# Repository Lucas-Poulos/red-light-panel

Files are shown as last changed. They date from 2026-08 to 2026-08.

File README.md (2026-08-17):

# red-light-panel

A battery-powered 660nm red light therapy panel. 4S2P 18650 Li-ion pack
(~74Wh-class), USB-C PD charging, ~74W LED load across two independently
PWM-dimmable channels, STM32-based control with a 4-button HMI.

KiCad 10 hardware project — schematic + BOM. PCB placement/routing is
out of scope for this pass, but the board is fab-ready to route against:
2-layer, 1oz/1oz copper, JLCPCB-standard-service design rules with
margin (not run at the fabrication limit) — see
`docs/pcb_fabrication_rules.md` for the exact values and rationale.
All 153 components are imported onto the board from the schematic.

## Architecture

Seven hierarchical sheets, numbered so KiCad's hierarchy navigator sorts
them in build/reading order:

| Sheet | Description |
|---|---|
| `01_battery_protection` | 4S2P 18650 pack, BQ76920 protection AFE, high-side dual-FET protection, reverse-polarity guard |
| `02_usbc_charging` | USB-C PD input (TPS25751), buck-boost charger (BQ25792), ESD protection |
| `03_power_rail_3v3` | TPS563201 buck regulator, 3.3V system logic rail |
| `04_led_drivers` | 2x LM3409HV PFET-buck constant-current LED driver channels |
| `05_led_array` | 64x Luminus SST-10-DR-B130-K660 660nm LEDs, 2 channels x 8 parallel x 4 series strings |
| `06_mcu_control` | STM32G031K8T6 MCU, SWD debug (Cortex Debug 10-pin + THT breakout), ESD arrays |
| `07_hmi` | 4 tactile buttons (power/dim+/dim-/mode), single-color status LED |

Connectivity uses `GlobalLabel`s throughout rather than wired
hierarchical sheet-symbol pins — see `docs/design_notes.md` for why. The
root sheet (`red-light-panel.kicad_sch`) contains only the 7 sheet
symbols, no components.

## Opening the project

Requires **KiCad 10**. Clone the repo and open `red-light-panel.kicad_pro`
— the project-local `sym-lib-table`/`fp-lib-table` register every stock
library this design uses (via `${KICAD10_SYMBOL_DIR}`/
`${KICAD10_FOOTPRINT_DIR}`, so they resolve on any machine with KiCad 10
installed) plus `libs/red-light-panel.kicad_sym` / `.pretty` for the
handful of parts not in KiCad's stock libraries. No global library setup
is required.

## Regenerating the schematics

The 7 sub-sheets and the root sheet are generated programmatically from
`tools/kicad_gen/` (a small `kiutils`-based builder), not hand-drawn —
see `docs/design_notes.md` "Schematic generation approach" for the full
pipeline and the non-obvious KiCad file-format details it works around.
To rebuild everything from the declarative part lists in
`tools/kicad_gen/sheet*.py`:

```
pip install kiutils sexpdata
python3 tools/kicad_gen/sheet1.py   # ... through sheet7.py
python3 tools/kicad_gen/root_sheet.py
python3 tools/kicad_gen/fix_instance_paths.py
```

## Regenerating the BOM

```
python3 bom/generate_bom.py
```

Wraps `kicad-cli sch export bom` (reads the full hierarchical netlist
including the custom `MPN`/`Manufacturer`/`DigiKey_PN`/`Sheet` fields set
on every symbol) grouped by `(MPN, Value, Footprint)` into
`bom/red-light-panel-bom.csv` — 48 rows, 153 total placed components.

## Current design status

**Verification**: full-hierarchy `kicad-cli sch erc` on
`red-light-panel.kicad_sch` reports **0 errors** (157 cosmetic
"endpoint off grid" warnings from the auto-placed layout, 3 expected
"lib_symbol_mismatch" warnings from stock parts whose KiCad-library
`extends` chain was flattened for pin-position reliability — see
`docs/design_notes.md`). Every one of the 153 placed components has a
linked footprint; zero duplicate reference designators.

### Known open items (flagged, need your review before fab)

**Corrections to the original BOM** (verified real part numbers/topology
fixes, not silent substitutions to different components):
- `TPD4S012DBVR` → **TPD4S012DRYR** (that BVR suffix/package doesn't
  exist for this part; TI only makes it in a 6-pin USON).
- `TPD4E001DZDR` → **TPD4E001DBVR** (same issue; the 4-channel device
  needs a 6-pin SOT-23, not the 4-pin DZD package).
- `TPS25750DRYR` → **TPS25751DREFR** (TPS25750 is TI-marked
  Not-Recommended-for-New-Designs; TPS25751 is the active replacement —
  your decision, see below).
- Fuse `MICROSMD250F/16-2` (originally a placeholder) → **Bel Fuse
  0ZRE0025FF** (0.25A hold current, matching the placeholder's own naming
  convention) — verify hold-current spec against your real current
  budget before finalizing.
- Status LED `APTD1608LSECK/J4-PRV` → confirmed **single-color**
  (`APT1608LSECK/J4-PRV`, no "D") — no real bi-color part exists under
  that family name. Per your decision, D71 (renumbered from D8, see
  below) is now a single-color status LED.
- Reference designators **D6/D7/D8 renumbered to D69/D70/D71**: the
  original BOM's own `D5-D68` (64 LED array elements) numerically
  collided with these three (sheet 6 ESD arrays, sheet 7 status LED).

**Needs your engineering review** (reasonable, documented, but
unverified-against-datasheet or genuinely open decisions):
- **BQ25792's front-end ideal-diode MOSFETs (ACFET/RBFET1/RBFET2) are not
  included** — TI's real reference design needs them on the
  ACDRV1/ACDRV2/BTST1/BTST2 pins, but they weren't itemized in the
  original BOM and weren't invented here unprompted. The charger's
  reverse-blocking front-end is incomplete as generated until you decide
  whether/how to add this.
- **TPS25751DREFR and BQ25792RQMR are hand-built symbols** (no official
  downloadable KiCad source exists for either — confirmed via TI/DigiKey/
  Ultra Librarian). Every pin was sourced from TI's own datasheet pin
  tables, but several individual pins have ambiguous datasheet electrical
  types (TI itself labels some pins as generic "P"/"I/O") — double-check
  before trusting blind, especially: TPS25751's `LDO_1V5`/`DRAIN`/`PPHV`/
  `VBUS_IN`; BQ25792's `BTST1`/`BTST2`/`VAC1`/`VAC2`/`BATP`/`BAT`/`PMID`.
- **TPS25751's power-path topology** (VBUS_IN → internal switch →
  PPHV/DRAIN → BQ25792) is a best-effort interpretation of TI's own
  ambiguous datasheet, not confirmed against a real TI reference design.
- **LED array topology** (8 parallel strings of 4 series LEDs per
  channel, ~625mA/string) is derived from Vf/rail-voltage math, not
  specified by the BOM — verify against the ~74W target power budget and
  the Luminus datasheet's thermal-derating curves.
- **STM32G031 GPIO assignment** (I2C on PB6/PB7, PWM on PA6/PA7, buttons
  on PA0-PA3, NTC ADC on PA4, NRST on PF2) is a reasonable but
  **unverified-against-the-reference-manual** pin choice.
- **Driver inductors** (L2/L3, Vishay IHLP2525CZERR10M01) and the 3.3V
  rail inductor (L1, Wurth 744031220) — values need a real switching-
  frequency calc against LM3409HV's/TPS563201's design equations, not
  just the default values used here.
- **L1's footprint** is a size-matched placeholder (no exact Wurth
  744031220 footprint exists in KiCad's stock libraries).
- **J3's exact GCT USB4105 suffix** (plating/stake length) — defaulted
  to `USB4105-GF-A`; there is no "mount style" suffix (confirmed via
  research — the whole series is one fixed SMT top-mount style).
- **J6's footprint** (generic 2x5 1.27mm SMD header) is electrically
  equivalent to but not the exact Samtec FTSH-105-01-F-DV-K footprint.
- **Calculated component values** flagged inline in their `Value` field
  wherever a real datasheet equation was used instead of an itemized BOM
  value: R3 (3.3V feedback divider bottom leg), R13 (status LED current
  limit), and every "(added, flagged)" support passive (COFF/UVLO
  networks, bootstrap caps, ILIM_HIZ/PROG set resistors, NTC pull-up) —
  see `tools/kicad_gen/sheet*.py` docstrings for the reasoning behind
  each.

None of the above are unresolved *nets* or missing pin connections —
every flagged item is a component-value/part-choice judgment call called
out for your review, consistent with a 0-error ERC pass.

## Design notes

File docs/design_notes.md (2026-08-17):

# Design notes

Working notes on non-obvious decisions made while generating this project,
kept here so they don't get lost or re-litigated later.

## Schematic generation approach

All 7 sub-sheets (and the root sheet) are generated programmatically from
`tools/kicad_gen/` rather than hand-drawn in the KiCad GUI, because the
BOM is large (~150 placed parts) and this keeps the part list, footprint
assignment, and wiring declarative and re-runnable. See
`tools/kicad_gen/builder.py` for the implementation; each `tools/kicad_gen/sheetN.py`
defines that sheet's parts and nets and calls into the shared builder.

You can still open and edit the resulting `.kicad_sch` files normally in
the KiCad 10 GUI -- the generator is just how they were first populated.

### Pipeline

1. Build the schematic object model with `kiutils` (a mature Python KiCad
   file library that targets the KiCad 8-era file format).
2. Text-patch two gaps between what kiutils emits and what KiCad 10 needs
   to load the file at all: quote the `generator` token and add a
   `generator_version` line (kiutils doesn't emit this token), and quote
   bare UUID-shaped tokens (kiutils doesn't quote them; KiCad 10's loader
   rejects the file outright without quotes).
3. Run `kicad-cli sch upgrade --force` to have the real KiCad 10 binary
   rewrite the file to its true native format. This is the authoritative
   normalization step -- nothing about the final file format is guessed.

### Connectivity: global labels, no wires

Every pin that needs to be on a net gets a `GlobalLabel` placed exactly at
that pin's world coordinate -- no wires anywhere. Two labels with the same
text are the same net project-wide even with zero wires between them, as
long as each is coincident with a real pin. This is standard KiCad
behavior (confirmed against a real kicad-cli 10.0.5 install and
cross-checked against a prior project's own ERC-clean, wire-free
schematics) and avoids hand-routing ~150 components.

**Global, not local, labels.** `LocalLabel` empirically did *not* connect
to a coincident pin in this KiCad version without an explicit wire
touching both -- only `GlobalLabel` (and, by extension, hierarchical
labels) connect by bare coincidence. Since every net name used here is
unique to its sheet except the intentionally-shared cross-sheet nets
(VBAT, GND, I2C_SDA, ...), using global scope throughout carries no risk
of accidental cross-sheet merges.

**Why global labels instead of sheet-symbol pins.** The prompt that
originated this project asked for literal hierarchical labels + matching
sheet-symbol pins on the root sheet for inter-sheet nets. Global labels
achieve the identical electrical outcome (a net crosses sheet boundaries
by name, project-wide) with far less risk -- no need to hand-place
sheet-symbol pins and wire them to matching labels on the root sheet, and
no chance of a sheet-pin/hierarchical-label name or direction mismatch.
The root sheet's sheet symbols carry no pins as a result; this is a
deliberate, documented substitution, not an oversight.

**Power nets use real power symbols, not bare labels.** GND, VBAT,
VBAT_PROT, 3V3, and USB_VBUS are placed as actual KiCad power symbols
(`power:GND`, `power:+3V3` with its Value overridden to "3V3",
`power:VBUS` overridden to "USB_VBUS", and two custom symbols for VBAT/
VBAT_PROT copied from stock `power:+BATT` into
`libs/red-light-panel.kicad_sym`) rather than plain `GlobalLabel`s -- the
idiomatic convention a human designer would use for rails specifically.
`add_power_symbol()` in `builder.py` places one at every pin on these
nets, same coincidence-based mechanism as the flying-label technique
above (confirmed empirically that overriding a stock power symbol's
Value *does* change its effective net name -- e.g. `power:+3V3` with
Value "3V3" correctly nets as "3V3", not "+3V3" -- as long as the symbol
is actually coincident with a real pin; an isolated power symbol
touching nothing is, unsurprisingly, still just as disconnected as an
isolated label would be). Every stock/custom power symbol's pin is type
`power_in`, never `power_out`, so this doesn't change anything about the
PWR_FLAG requirements below. All other cross-sheet/signal nets
(I2C_SDA, PWM_A, LED_A+, ...) remain plain `GlobalLabel`s -- a "power
symbol" wouldn't make semantic sense for a data or PWM signal.

**The pin-position Y-flip.** A pin's world connection point is
`(symbol.x + pin.local_x, symbol.y - pin.local_y)` -- note the minus sign.
KiCad's symbol library editor uses a Y-up coordinate system internally,
but placed schematic coordinates are Y-down, so the Y axis flips when a
symbol is placed. Confirmed empirically (a naive `+` produced schematics
where every single pin was reported "not connected" by
`kicad-cli sch erc`, despite the labels looking coincident on paper) and
cross-checked against a real, ERC-clean prior project's file. Pin `length`
is *not* added -- the pin's own `(at x y)` already is the connection tip
in the library data kiutils exposes.

**Flattening `extends`-based symbols.** A handful of stock symbols
(`Transistor_FET:AO3401A` extends `TP0610T`, `CSD18540Q5B` extends
`Q_NMOS_SSSGD_AvalancheRated`) are defined via KiCad's `extends`
mechanism to avoid duplicating a shared body/pinout. Embedding both the
derived and base symbols in a sheet's `lib_symbols` cache (with the base's
library correctly registered in the project's own `sym-lib-table`) loads
fine and only produces the expected benign `lib_symbol_mismatch` ERC
warning -- but pin *position* resolution for the still-`extends`-linked
placed instance did not reliably line up with the raw coordinates pulled
from the base symbol: every pin on every `extends`-based part came back
as a dangling label. `load_stock_symbol()` in `builder.py` works around
this by flattening -- copying the base's units directly onto the derived
symbol and dropping the `extends` pointer before embedding, so pin data
always comes from the one object that's actually placed. A prior project
independently hit and documented the same class of problem (there, the
proximate cause was an unregistered library nickname rather than a
pin-position mismatch, but the fix -- flatten `extends` rather than rely
on it -- is the same).

### PWR_FLAG placement

`kicad-cli sch erc`'s `power_pin_not_driven` check requires every
`power_in`-type pin's net to have some `power_out`-type pin (or a
`Device:PWR_FLAG`) on it *somewhere in the whole hierarchical project*.
Rails that are genuinely sourced off-sheet from that sheet's own
perspective (e.g. `VBAT` and `GND` on the battery sheet, which are
sourced by the cell stack itself and by downstream loads respectively, not
by any `power_out` pin placed on that sheet) get a `PWR_FLAG` so this
check doesn't misfire. `PWR_FLAG` symbols are placed with `in_bom no` /
`on_board no`, matching KiCad convention -- they're a paper annotation for
ERC, not a real component.

**Exactly one `PWR_FLAG` per net, project-wide.** Placing one per sheet
(the initial approach, since each sheet's ERC was validated standalone
before the root hierarchy existed) breaks at full-hierarchy scale: two or
more `PWR_FLAG`s on the same merged global-label net trigger their own
`pin_to_pin` "Power output and Power output are connected" error against
each other. Also: a pin typed `output` (e.g. a buck regulator's `SW` pin)
does *not* satisfy `power_pin_not_driven` the way a `power_out`-typed pin
does -- don't assume a rail is "genuinely driven" without checking the
actual electrical type of the pin that's supposed to be driving it.

**Each `PWR_FLAG`'s `Reference` must be unique project-wide.** Every
instance defaulting to the literal `#FLG` (rather than an
auto-incrementing `#FLG1`, `#FLG2`, ...) is invisible to `kicad-cli sch
erc` but trips `kicad-cli sch export bom`'s annotation check once more
than one exists across the hierarchy -- a real KiCad GUI session
auto-numbers these the first time you run Annotate, but nothing here ever
calls that, so `add_pwr_flag()` takes an explicit `flag_id` argument.

### Root sheet: per-symbol `instances` blocks

`kicad-cli sch upgrade --force` (used while generating/validating each
sheet standalone, before the root sheet existed) silently drops every
placed symbol's `(instances (project ...))` block down to an empty
`(instances)` -- observed empirically, not something this project's code
or kiutils ever asked it to do. That's invisible to ERC (which works from
raw geometry) but is exactly what `kicad-cli sch export bom` flags as
"schematic has annotation errors": each symbol's project-instance
bookkeeping (which sheet-instance path it belongs to) was empty.
`tools/kicad_gen/fix_instance_paths.py` is a one-time pass, run after the
root sheet exists, that populates the real path
(`/<root-uuid>/<this-sheet's-uuid-on-the-root-sheet>`) via direct text
surgery -- round-tripping an already-v10-upgraded file back through
kiutils was tried first and rejected: kiutils' parser doesn't fully
understand the v10 format `kicad-cli` produces and silently drops most of
the file's content on that round-trip (a 6,300-line file came back as
~2,100 lines with no error raised).

### Reference-designator collision in the original BOM

The brief's own BOM has a numbering collision: `D5-D68` (64 LED array
elements, sheet 5) numerically includes `D6`/`D7` (sheet 6's ESD arrays)
and `D8` (sheet 7's status LED). Resolved by keeping the LED array's
documented range intact (it has an exact count constraint: 68-5+1=64) and
renumbering the other three to `D69`/`D70`/`D71` instead. Flagged in each
affected sheet's build-script docstring.

## Flagged additions beyond the literal BOM

A few passives are required by the datasheet-mandated minimum application
circuit for a listed IC, but weren't itemized as separate BOM rows in the
original part list. These are called out with `(added, flagged)` in their
`Value` field and documented per-sheet in that sheet's build script
docstring (`tools/kicad_gen/sheetN.py`) so they're easy to find and
double-check. See also the top-level `README.md` "Known open items" list.

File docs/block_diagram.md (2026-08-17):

# Block diagram

Placeholder — a visual block diagram should go here (e.g. exported from
the KiCad hierarchy or drawn separately). Textual summary of the signal
flow in the meantime:

```
USB-C (J3) ──► TPS25751 (PD sink + power path) ──► BQ25792 (buck-boost charger) ──► VBAT
                                                                                        │
4S2P 18650 pack ───────────────────────────────────────────────────────────────────────┤
                                                                                        ▼
                                                              BQ76920 (protection AFE)
                                                              + high-side dual-FET guard
                                                                                        │
                                                                                        ▼
                                                                                  VBAT_PROT
                                                                                        │
                                        ┌───────────────────────────────────────────────┼──────────────┐
                                        ▼                                               ▼              ▼
                              TPS563201 (3.3V buck)                          LM3409HV x2 (LED drivers, PWM_A/PWM_B from MCU)
                                        │                                               │
                                        ▼                                               ▼
                          STM32G031K8T6 (MCU) ◄──── HMI (4 buttons)          LED array (64x 660nm, 2ch x 8 parallel x 4 series)
                                        │
                                        ▼
                                 SWD debug (J6/J7)
```

Fill in with the actual rationale/tradeoffs discussed separately once
available (referenced in the original project brief as "I'll fill in
details from our chat separately").

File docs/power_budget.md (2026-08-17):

# Power budget notes

Placeholder — rough, back-of-envelope numbers derived while generating
the schematic (see `tools/kicad_gen/sheet4.py` and `sheet5.py` docstrings
for the full reasoning). **Not a substitute for a real power budget
pass** — flagged throughout as needing verification against the actual
Luminus SST-10-DR datasheet current/thermal-derating curves and your
real target runtime.

## LED load

- 64x Luminus SST-10-DR-B130-K660, split into 2 channels (LM3409HV
  drivers) x 8 parallel strings x 4 series LEDs.
- ~2.1V Vf per LED (typ., 660nm deep red) → ~8.4V per string.
- LM3409HV/R4-R5 sense resistor (0.02ohm, ~100mV typ. threshold) sets
  ~5A total channel current → ~625mA per string/per LED.
- Per-channel: ~8.4V x 5A ≈ 42W. Two channels ≈ **84W** -- in the same
  ballpark as the brief's own "~74W LED load" figure but not an exact
  match; needs reconciling against your actual target (adjust the sense
  resistor value or string count to dial in the real target current).

## Battery pack

- 4S2P 18650 (e.g. Samsung INR18650-30Q, ~3000mAh/cell) → ~6000mAh pack
  capacity at nominal 14.4V (3.6V/cell) → **~86Wh** pack energy.
- At ~84W LED load alone (both channels, ignoring MCU/driver overhead),
  that's roughly **~1 hour** of runtime at full brightness/both channels
  -- worth checking against your actual intended treatment-session
  duration and duty cycle (PWM dimming via EN on the LM3409HV channels
  will reduce average draw well below this worst-case number in normal
  use).

## Charging

- BQ25792 buck-boost charger, USB-C PD input via TPS25751. Real charge
  current depends on the PD contract negotiated (not modeled here) and
  the ILIM_HIZ/PROG resistor values (R91/R92, flagged as placeholders in
  `sheet2.py` -- calculate against your real target charge current).

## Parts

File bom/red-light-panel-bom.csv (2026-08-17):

Reference | Value | MPN | Manufacturer | DigiKey_PN | Qty | Sheet
BT1,BT2,BT3,BT4,BT5,BT6,BT7,BT8 | INR18650-30Q | Samsung INR18650-30Q | Samsung SDI | INR18650-30Q-B-ND | 8 | 1
C1,C2,C6,C12,C13 | 10uF | CC1206KKX7R8BB106 | Yageo | 311-4622-1-ND | 5 | 2,3,4
C3,C4,C5,C8,C9,C10,C11,C14,C15,C16,C17 | 0.1uF | CC0603KRX7R9BB104 | Yageo | 311-1367-1-ND | 11 | 2,4,6
C7 | 10uF | CC1206KKX5R7BB106 | Yageo | 311-4633-1-ND | 1 | 3
C18 | 4.7uF | CC1206KKX7R8BB475 | Yageo | 311-4646-1-ND | 1 | 6
C90 | 1uF (added, flagged) |  |  |  | 1 | 1
C91 | 0.1uF (added, flagged) |  |  |  | 1 | 1
C92 | 1uF (added, flagged -- PMID bulk cap per typical app circuit) |  |  |  | 1 | 2
C93 | 2.2nF (added, flagged -- VBST bootstrap cap) |  |  |  | 1 | 3
C94,C95 | 100pF (added, flagged -- COFF timing, calc vs L freq) |  |  |  | 2 | 4
D1 | SMAJ24CA | SMAJ24CA | Littelfuse | F5351CT-ND | 1 | 1
D2 | TPD4S012DRYR (corrected from BOM's TPD4S012DBVR -- flag) | TPD4S012DRYR | Texas Instruments | 296-TPD4S012DRYRCT-ND | 1 | 2
D3,D4 | SS54 | SS54 | onsemi/Diodes Inc (generic SS54) | SS54-E3/57TCT-ND | 2 | 4
D5,D6,D7,D8,D9,D10,D11,D12,D13,D14,D15,D16,D17,D18,D19,D20,D21,D22,D23,D24,D25,D26,D27,D28,D29,D30,D31,D32,D33,D34,D35,D36,D37,D38,D39,D40,D41,D42,D43,D44,D45,D46,D47,D48,D49,D50,D51,D52,D53,D54,D55,D56,D57,D58,D59,D60,D61,D62,D63,D64,D65,D66,D67,D68 | SST-10-DR-B130-K660 | SST-10-DR-B130-K660 | Luminus Devices | 1462-SST-10-DR-B130-K660-ND (verify exact reel/tape SKU) | 64 | 5
D69,D70 | TPD4E001DBVR (corrected from BOM's TPD4E001DZDR -- flag) | TPD4E001DBVR | Texas Instruments | 296-TPD4E001DBVRCT-ND | 2 | 6
D71 | APT1608LSECK/J4-PRV (single-color, corrected per your decision) | APT1608LSECK/J4-PRV | Kingbright | 754-1552-1-ND | 1 | 7
F1 | 0.25A resettable | 0ZRE0025FF (corrected from placeholder MICROSMD250F/16-2 -- FLAG FOR REVIEW) | Bel Fuse | 507-1677-1-ND | 1 | 1
J1 | JST B5B-XH-A | B5B-XH-A | JST | 455-1719-ND | 1 | 1
J2 | Molex 43045-0200 | 43045-0200 | Molex | WM1857-ND | 1 | 1
J3 | USB4105-GF-A (plating/stake length TBD, flag) | USB4105-GF-A | GCT | GCT USB4105-GF-A-ND (verify exact DigiKey SKU) | 1 | 2
J4,J5 | 2-pin screw terminal / JST-PH-2 | B2B-PH-K-S(LF)(SN) | JST | 455-1728-ND | 2 | 5
J6 | Cortex Debug 10-pin | FTSH-105-01-F-DV-K (footprint substituted, flag) | Samtec | SAM8199-ND | 1 | 6
J7 | Debug breakout (SWDIO,SWCLK,NRST,3.3V,GND) | PREC005SAAN-RC | Sullins | S7036-ND | 1 | 6
L1 | 2.2uH (Wurth 744031220) | 744031220 | Wurth Elektronik | 732-1801-1-ND | 1 | 3
L2,L3 | IHLP2525CZERR10M01 (0.10uH) | IHLP2525CZERR10M01 | Vishay Dale | 541-2724-1-ND | 2 | 4
L90 | 2.2uH (added, flagged -- calc vs target charge current) |  |  |  | 1 | 2
Q1,Q2 | CSD18540Q5B | CSD18540Q5B | Texas Instruments | 296-37312-1-ND | 2 | 1
Q3 | AO3401A | AO3401A | Alpha & Omega Semiconductor | AO3401A-DICT-ND | 1 | 1
Q4,Q5 | AO3401A (30V Vds, satisfies brief's margin flag) | AO3401A | Alpha & Omega Semiconductor | AO3401A-DICT-ND | 2 | 4
R1 | 0.01R 1% | WSL2512R0100FEA | Vishay Dale | 541-2455-1-ND | 1 | 1
R2,R6,R7,R8,R9,R10,R11,R12 | 10k | RC0603FR-0710KL | Yageo | 311-10.0KHRCT-ND | 8 | 3,6,7
R3 | 3.01k (calc, flag) | RC0603FR-073K01L | Yageo | 311-3.01KHRCT-ND | 1 | 3
R4,R5 | 0.02R 1% | WSL2512R0200FEA | Vishay Dale | 541-2456-1-ND | 2 | 4
R13 | 680R (calc vs Vf/If, flag) | RC0603FR-07680RL | Yageo | 311-680HRCT-ND | 1 | 7
R90 | 100k | RC0603FR-07100KL | Yageo | 311-100KHRCT-ND | 1 | 1
R91 | 10k (added, flagged -- ILIM_HIZ set resistor, calc per datasheet eqn) |  |  |  | 1 | 2
R92 | 4.7k (added, flagged -- PROG set resistor, calc per datasheet eqn) |  |  |  | 1 | 2
R94,R96 | 100k (added, flagged -- COFF timing, calc vs L freq) |  |  |  | 2 | 4
R95,R97 | 100k (added, flagged -- UVLO always-on pull-up, no set threshold) |  |  |  | 2 | 4
R98 | 10k (added, flagged -- NTC divider pull-up) |  |  |  | 1 | 5
RT1 | NCP18XH103F03RB (10k NTC) | NCP18XH103F03RB | Murata | 490-16279-1-ND | 1 | 5
SW1,SW2,SW3,SW4 | Omron B3U-1000P | B3U-1000P | Omron | SW1020CT-ND | 4 | 7
U1 | BQ76920PW | BQ7692000PWR | Texas Instruments | 296-37299-1-ND | 1 | 1
U2 | TPS25751DREFR (active replacement for NRND TPS25750DRYR, per your decision) | TPS25751DREFR | Texas Instruments | 296-TPS25751DREFR-ND (verify) | 1 | 2
U3 | BQ25792RQMR | BQ25792RQMR | Texas Instruments | 296-BQ25792RQMR-ND (verify) | 1 | 2
U4 | TPS563201DDCR | TPS563201DDCR | Texas Instruments | 296-51654-1-ND | 1 | 3
U5,U6 | LM3409HVMY/NOPB | LM3409HVMY/NOPB | Texas Instruments | 296-30489-1-ND | 2 | 4
U7 | STM32G031K8T6 | STM32G031K8T6 | STMicroelectronics | 497-STM32G031K8T6TR-ND | 1 | 6

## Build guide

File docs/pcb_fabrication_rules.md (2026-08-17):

# PCB fabrication rules — 2-layer, 1oz/1oz, JLCPCB standard service + margin

This board is configured as a standard (non-advanced/non-HDI) 2-layer
JLCPCB build, with every constraint set comfortably above JLCPCB's
published minimum capability rather than at the limit. Two places hold
the actual rule values:

- **`red-light-panel.kicad_pro`** (`board.design_settings.rules` and
  `net_settings.classes`) — board-wide minimums, edited in KiCad's own
  "Board Setup > Design Rules > Constraints" schema.
- **`red-light-panel.kicad_dru`** — net-specific overrides for
  high-current traces (KiCad auto-loads this because its filename
  matches the project name; no separate registration needed).

## Stackup

`red-light-panel.kicad_pcb`'s `(setup (stackup ...))`:

| Layer | Spec |
|---|---|
| F.Cu / B.Cu | 1oz (0.035mm) copper, both outer layers |
| Core | 1.53mm FR4 core, er=4.6, loss tangent 0.02 (JLCPCB's commonly published 2-layer 1.6mm-stackup core) |
| Overall thickness | 1.6mm (standard, matches `general.thickness`) |
| Surface finish | **ENIG**, not JLCPCB's HASL default |

**Surface finish flag**: this design has fine-pitch QFN parts (BQ25792
at 0.4mm pitch, TPS25751 also 0.4mm pitch) where HASL's uneven surface
is a real solder-bridging risk. ENIG is still a standard JLCPCB service
option (not an "advanced" surcharge tier), just a deliberate upgrade
from their default. Flip back to HASL if cost is a bigger concern than
that risk for your build.

## Board-wide DRC minimums (`kicad_pro` → `design_settings.rules`)

| Rule | JLCPCB standard-service minimum | Set here | Margin |
|---|---|---|---|
| Track width | 0.09mm (3.5mil) | **0.15mm (6mil)** | ~1.7x |
| Clearance (track/pad-to-track/pad) | 0.09mm (3.5mil) | **0.15mm (6mil)** | ~1.7x |
| Copper-to-board-edge | ~0.3mm | **0.5mm** (kept from KiCad's own default, already exceeds target) | ~1.7x |
| Hole-to-copper clearance | ~0.13mm | **0.3mm** | ~2.3x |
| Hole-to-hole spacing | ~0.25mm | **0.5mm** | 2x |
| Through-hole (PTH) diameter | ~0.2-0.3mm (board-thickness dependent) | **0.3mm** | at/above min |
| Via diameter (pad) | ~0.45mm | **0.5mm** floor / **0.6mm** preferred (net class) | modest, more via the preferred-vs-floor gap |
| Via drill | ~0.2mm | **0.3mm** (net class default) | 1.5x |
| Silk line width | ~0.1mm (4mil) | **0.15mm (6mil)** | 1.5x |
| Silk clearance | not separately specified | **0.15mm** | -- |
| Min text height | 0.8mm (legibility floor) | **1.0mm** | -- |
| Solder mask expansion | ~0.05mm typical default | **0.05mm** | matches typical, not pushed to 0 |

6mil track/clearance (not JLCPCB's bare 3.5mil minimum) is a
widely-used "PCB house safe default" across the industry generally, not
just JLCPCB-specific — it's tight enough to still be practical for this
board's finer-pitch parts, while leaving real headroom over the absolute
floor.

**Known tension, flagged rather than silently loosened**: JLCPCB's
0.4mm/0.5mm-pitch QFN parts (BQ25792, TPS25751, LM3409HV) may need
tighter local escape-routing clearance than this board-wide 0.15mm floor
allows once layout begins — that's a normal, expected situation handled
with a small *local* net-class exception for just those specific escape
traces when routing, not by loosening the global minimum for the whole
board. Not resolved here since layout hasn't started.

## Net-specific high-current overrides (`kicad_dru`)

The board-wide 0.15mm minimum is nowhere near adequate for actual
current-carrying traces — this is a real physical/thermal constraint,
not a fabrication-capability one, and needed handling regardless of the
DRC-minimum discussion above. Per `docs/power_budget.md`'s ~5A/channel
LED current and comparable pack-level current estimates, 1oz copper at
~20°C rise wants meaningfully wider traces than logic-signal minimums:

| Net group | Track width | Rationale |
|---|---|---|
| `VBAT`, `VBAT_PROT`, `GND`, `USB_VBUS`, `PD_PP_OUT` | 1.5mm (opt), 1mm (min) | Pack-level current, worst case ~5-6A |
| `LED_A+/-`, `LED_B+/-` | 1.5mm (opt), 1mm (min) | ~625mA/string x up to 8 parallel strings ≈ 5A/channel |
| `U4_SW`, `U3_SW1`, `U3_SW2` | 1mm (opt), 0.8mm (min) | Buck/charger switching nodes -- also keep these short/direct once routed, wide alone doesn't fix switching-noise loop area |

These widths are a safe starting point sized off the power-budget
estimate already flagged as needing real verification (see
`docs/power_budget.md`) — recheck once the exact target LED current is
locked in, not just before fab.

## Current DRC status

The board currently has all 153 footprints imported from the schematic
but **not yet placed or routed** (this project's stated scope stopped at
schematic + BOM — see `README.md`). Running `kicad-cli pcb drc` right
now reports several hundred violations, essentially all attributable to
that: overlapping default-import footprint placement (`shorting_items`,
`clearance`, `silk_overlap`/`silk_over_copper`), no board outline
(`invalid_outline`), and pad nets not yet synced from the schematic
(`net_conflict` under schematic-parity). None of that is caused by the
rule values above — it's expected for an unplaced/unrouted board and
will clear as layout progresses.

One **real, useful finding** the new rules did catch: **U2's WQFN-38
footprint** (`Package_DFN_QFN:Texas_REF0038A_WQFN-38-2EP_6x4mm_P0.4`)
has small thermal-relief vias in its exposed pad drilled at 0.2mm,
which is below this board's 0.3mm minimum through-hole diameter. This
is the same footprint already flagged in `README.md` as having a
pad-count-mismatch caveat from sourcing — worth resolving both issues
together when this footprint gets a closer look (either accept 0.2mm
thermal vias as a deliberate, JLCPCB-capable-but-tighter-than-our-margin
exception for just that footprint, or rebuild the thermal pad via array
at 0.3mm).

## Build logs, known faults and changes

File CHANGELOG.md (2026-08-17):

# Changelog

All notable changes to this project are documented here.

## [Unreleased]

### Added
- Initial repo scaffold: CERN-OHL-P v2 license, KiCad-appropriate
  `.gitignore`, README.
- KiCad 10 project scaffold (`red-light-panel.kicad_pro`/`.kicad_pcb`),
  project-scoped `sym-lib-table`/`fp-lib-table`.
- Programmatic schematic generator (`tools/kicad_gen/`) built on
  `kiutils`, used to populate all 7 hierarchical sub-sheets and the root
  sheet from declarative part lists.
- Full 7-sheet schematic hierarchy: Battery Pack & Protection, USB-C
  Charging Input, 3.3V Logic Rail, LED Drivers, LED Array, MCU & Control,
  HMI. 153 placed components, 0 ERC errors project-wide.
- Hand-built KiCad symbols for parts with no official downloadable source
  (`libs/red-light-panel.kicad_sym`): TPS25751DREFR, BQ25792RQMR,
  LM3409HVMY, TPD4S012DRYR, TPD4E001DBVR.
- Custom footprint for the Luminus SST-10-DR 3535-package LED
  (`libs/red-light-panel.pretty/`).
- BOM generation script (`bom/generate_bom.py`) and initial
  `bom/red-light-panel-bom.csv` (48 grouped rows).
- `docs/design_notes.md`, `docs/block_diagram.md`, `docs/power_budget.md`.

### Changed / corrected from the original part list
- `TPS25750DRYR` → `TPS25751DREFR` (NRND → active replacement).
- `TPD4S012DBVR` → `TPD4S012DRYR` (real part number for this device).
- `TPD4E001DZDR` → `TPD4E001DBVR` (real part number for this device).
- Placeholder fuse `MICROSMD250F/16-2` → Bel Fuse `0ZRE0025FF`.
- Status LED `APTD1608LSECK/J4-PRV` → confirmed single-color
  `APT1608LSECK/J4-PRV` (no real bi-color part exists under that name).
- Reference designators D6/D7/D8 renumbered to D69/D70/D71 (collided
  with the LED array's D5-D68 range).

See `README.md` "Known open items" for the full list of flagged
judgment calls still needing review.

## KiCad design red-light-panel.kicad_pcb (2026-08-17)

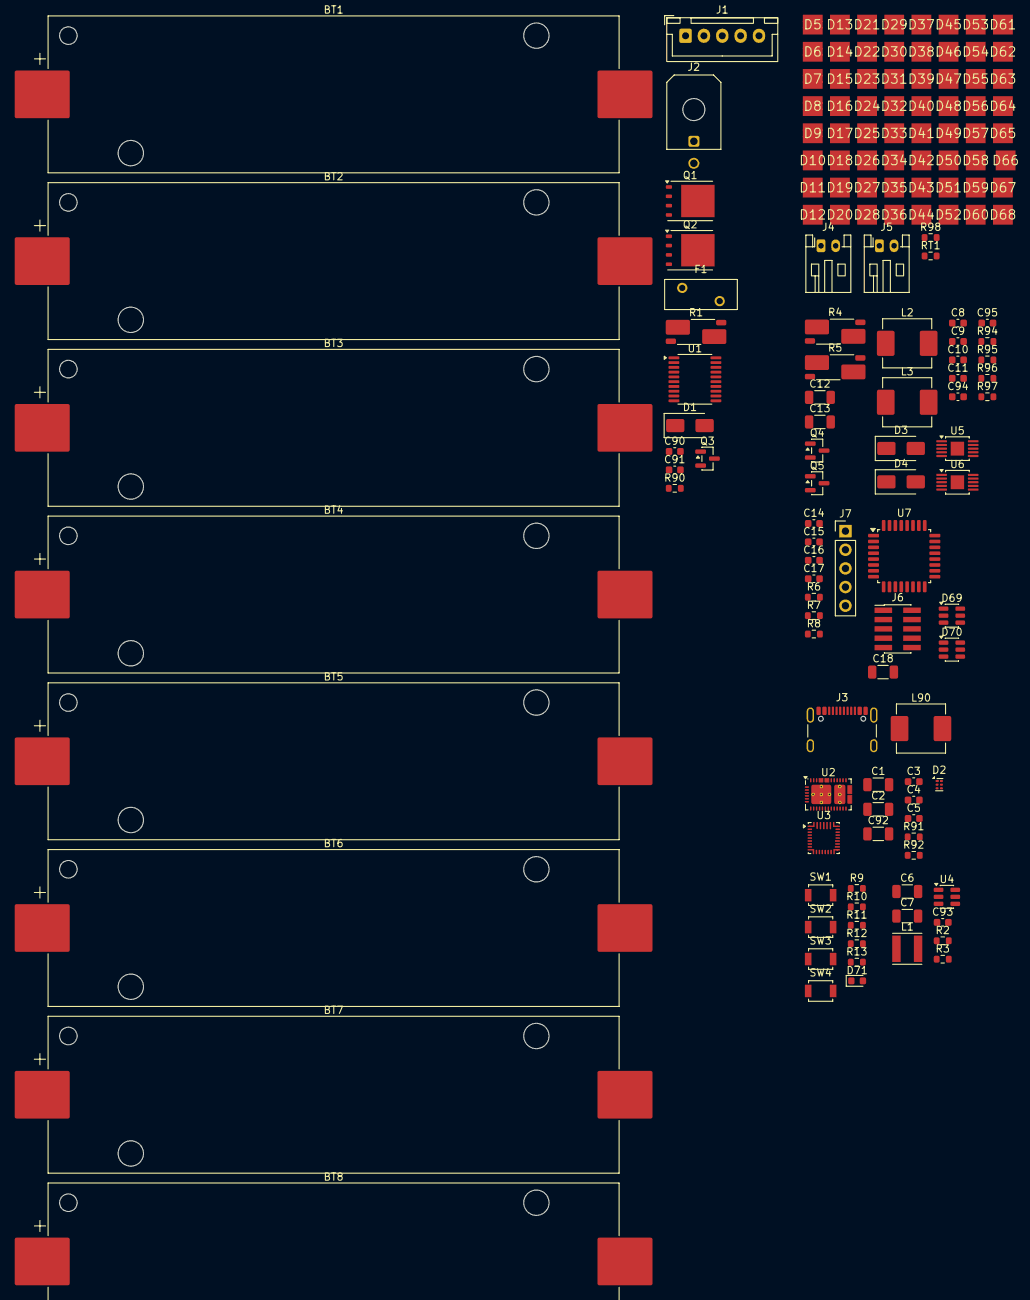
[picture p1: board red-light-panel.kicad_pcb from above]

Board: 2 copper layers, 153 parts (0 on the bottom side), 98 nets, no tracks yet.

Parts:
BT1, BT2, BT3, BT4, BT5, BT6, BT7, BT8: INR18650-30Q; BatteryHolder_Keystone_1042_1x18650
C1, C2, C6, C7, C12, C13: 10uF; C_1206_3216Metric
C3, C4, C5, C8, C9, C10, C11, C14, C15, C16, C17: 0.1uF; C_0603_1608Metric
C18: 4.7uF; C_1206_3216Metric
C90: 1uF (added, flagged); C_0603_1608Metric
C91: 0.1uF (added, flagged); C_0603_1608Metric
C92: 1uF (added, flagged -- PMID bulk cap per typical 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; C_1206_3216Metric
C93: 2.2nF (added, flagged -- VBST bootstrap cap); C_0603_1608Metric
C94, C95: 100pF (added, flagged -- COFF timing, calc vs L f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; C_0603_1608Metric
D1: SMAJ24CA; D_SMA
D2: TPD4S012DRYR (corrected from BOM's TPD4S012DBVR -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; Texas_USON-6_1x1.45mm_P0.5mm_SMD
D3, D4: SS54; D_SMA
D5, D6, D7, D8, D9, D10, D11, D12, D13, D14, D15, D16, D17, D18, D19, D20, D21, D22, D23, D24, D25, D26, D27, D28, D29, D30, D31, D32, D33, D34, D35, D36, D37, D38, D39, D40, D41, D42, D43, D44, D45, D46, D47, D48, D49, D50, D51, D52, D53, D54, D55, D56, D57, D58, D59, D60, D61, D62, D63, D64, D65, D66, D67, D68: SST-10-DR-B130-K660; LUMINUS_SST-10-3535
D69, D70: TPD4E001DBVR (corrected from BOM's TPD4E001DZDR -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; SOT-23-6
D71: APT1608LSECK/J4-PRV (single-color, corrected per 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; LED_0603_1608Metric
F1: 0.25A resettable; Fuse_BelFuse_0ZRE0025FF_L9.6mm_W3.8mm
J1: JST B5B-XH-A; JST_XH_B5B-XH-A_1x05_P2.50mm_Vertical
J2: Molex 43045-0200; Molex_Micro-Fit_3.0_43045-0200_2x01_P3.00mm_Horizontal
J3: USB4105-GF-A (plating/stake length TBD, flag); USB_C_Receptacle_GCT_USB4105-xx-A_16P_TopMnt_Horizontal
J4, J5: 2-pin screw terminal / JST-PH-2; JST_PH_S2B-PH-K_1x02_P2.00mm_Horizontal
J6: Cortex Debug 10-pin; PinHeader_2x05_P1.27mm_Vertical_SMD
J7: Debug breakout (SWDIO,SWCLK,NRST,3.3V,GND); PinHeader_1x05_P2.54mm_Vertical
L1: 2.2uH (Wurth 744031220); L_Vishay_IFSC-1515AH_4x4x1.8mm
L2, L3: IHLP2525CZERR10M01 (0.10uH); L_Vishay_IHLP-2525
L90: 2.2uH (added, flagged -- calc vs target charge cu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; L_Vishay_IHLP-2525
Q1, Q2: CSD18540Q5B; TDSON-8-1
Q3: AO3401A; SOT-23
Q4, Q5: AO3401A (30V Vds, satisfies brief's margin flag); SOT-23
R1: 0.01R 1%; R_Shunt_Vishay_WSK2512_6332Metric_T2.21mm
R2, R6, R7, R8, R9, R10, R11, R12: 10k; R_0603_1608Metric
R3: 3.01k (calc, flag); R_0603_1608Metric
R4, R5: 0.02R 1%; R_Shunt_Vishay_WSK2512_6332Metric_T2.21mm
R13: 680R (calc vs Vf/If, flag); R_0603_1608Metric
R90: 100k; R_0603_1608Metric
R91: 10k (added, flagged -- ILIM_HIZ set resistor, cal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; R_0603_1608Metric
R92: 4.7k (added, flagged -- PROG set resistor, calc p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; R_0603_1608Metric
R94, R96: 100k (added, flagged -- COFF timing, calc vs L fr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; R_0603_1608Metric
R95, R97: 100k (added, flagged -- UVLO always-on pull-up, n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; R_0603_1608Metric
R98: 10k (added, flagged -- NTC divider pull-up); R_0603_1608Metric
RT1: NCP18XH103F03RB (10k NTC); R_0603_1608Metric
SW1, SW2, SW3, SW4: Omron B3U-1000P; SW_SPST_B3U-1000P
U1: BQ76920PW; TSSOP-20_4.4x6.5mm_P0.65mm
U2: TPS25751DREFR (active replacement for NRND TPS257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; Texas_REF0038A_WQFN-38-2EP_6x4mm_P0.4
U3: BQ25792RQMR; Texas_RQM0029A_VQFN-29_4x4mm_P0.4mm
U4: TPS563201DDCR; SOT-23-6
U5, U6: LM3409HVMY/NOPB; HVSSOP-10-1EP_3x3mm_P0.5mm_EP1.83x1.89mm
U7: STM32G031K8T6; LQFP-32_7x7mm_P0.8mm

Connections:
3V3: C7.1, C14.1, C15.1, C16.1, C17.1, C18.1, D69.6 (VCC), D70.6 (VCC), J6.1 (VTref), J7.4, L1.2, R2.1, R6.1, R7.1, R8.1, R13.1, R98.1, SW1.1, SW2.1, SW3.1, SW4.1, U7.4 (VDD)
BTN_DIMM: D69.4 (IO3), R11.1, SW3.2, U7.9 (PA2)
BTN_DIMP: D69.3 (IO2), R10.1, SW2.2, U7.8 (PA1)
BTN_MODE: D69.5 (IO4), R12.1, SW4.2, U7.10 (PA3)
BTN_PWR: D69.1 (IO1), R9.1, SW1.2, U7.7 (PA0)
D8_A: D71.2 (A), R13.2
FET_MID: Q1.1 (S), Q1.2 (S), Q1.3 (S), Q2.1 (S), Q2.2 (S), Q2.3 (S)
GND: C1.2, C2.2, C3.2, C4.2, C5.2, C6.2, C7.2, C8.2, C9.2, C10.2, C11.2, C14.2, C15.2, C16.2, C17.2, C18.2, C90.2, C91.2, C92.2, C94.2, C95.2, D1.2 (A2), D2.4 (GND), D3.2 (A), D4.2 (A), D69.2 (GND), D70.2 (GND), J3.A1 (GND), J3.A12 (GND), J3.B1 (GND), J3.B12 (GND), J3.SH (SHIELD), J6.3 (GND), J6.5 (GND), J6.9 (GNDDetect), J7.5, R1.2, R3.2, R9.2, R10.2, R11.2, R12.2, R91.2, R92.2, RT1.2, U4.1 (GND), U5.5 (GND), U5.11 (DAP), U6.5 (GND), U6.11 (DAP), U7.5 (VSS)
I2C_SCL: R7.2, U7.30 (PB6)
I2C_SDA: R6.2, U7.31 (PB7)
LED_A+: C12.1, D5.2 (A), D9.2 (A), D13.2 (A), D17.2 (A), D21.2 (A), D25.2 (A), D29.2 (A), D33.2 (A), J4.1, L2.2
LED_A-: C12.2, D8.1 (K), D12.1 (K), D16.1 (K), D20.1 (K), D24.1 (K), D28.1 (K), D32.1 (K), D36.1 (K), J4.2, R4.1, U5.8 (CSP)
LED_A_S0_N0: D5.1 (K), D6.2 (A)
LED_A_S0_N1: D6.1 (K), D7.2 (A)
LED_A_S0_N2: D7.1 (K), D8.2 (A)
LED_A_S1_N0: D9.1 (K), D10.2 (A)
LED_A_S1_N1: D10.1 (K), D11.2 (A)
LED_A_S1_N2: D11.1 (K), D12.2 (A)
LED_A_S2_N0: D13.1 (K), D14.2 (A)
LED_A_S2_N1: D14.1 (K), D15.2 (A)
LED_A_S2_N2: D15.1 (K), D16.2 (A)
LED_A_S3_N0: D17.1 (K), D18.2 (A)
LED_A_S3_N1: D18.1 (K), D19.2 (A)
LED_A_S3_N2: D19.1 (K), D20.2 (A)
LED_A_S4_N0: D21.1 (K), D22.2 (A)
LED_A_S4_N1: D22.1 (K), D23.2 (A)
LED_A_S4_N2: D23.1 (K), D24.2 (A)
LED_A_S5_N0: D25.1 (K), D26.2 (A)
LED_A_S5_N1: D26.1 (K), D27.2 (A)
LED_A_S5_N2: D27.1 (K), D28.2 (A)
LED_A_S6_N0: D29.1 (K), D30.2 (A)
LED_A_S6_N1: D30.1 (K), D31.2 (A)
LED_A_S6_N2: D31.1 (K), D32.2 (A)
LED_A_S7_N0: D33.1 (K), D34.2 (A)
LED_A_S7_N1: D34.1 (K), D35.2 (A)
LED_A_S7_N2: D35.1 (K), D36.2 (A)
LED_B+: C13.1, D37.2 (A), D41.2 (A), D45.2 (A), D49.2 (A), D53.2 (A), D57.2 (A), D61.2 (A), D65.2 (A), J5.1, L3.2
LED_B-: C13.2, D40.1 (K), D44.1 (K), D48.1 (K), D52.1 (K), D56.1 (K), D60.1 (K), D64.1 (K), D68.1 (K), J5.2, R5.1, U6.8 (CSP)
LED_B_S0_N0: D37.1 (K), D38.2 (A)
LED_B_S0_N1: D38.1 (K), D39.2 (A)
LED_B_S0_N2: D39.1 (K), D40.2 (A)
LED_B_S1_N0: D41.1 (K), D42.2 (A)
LED_B_S1_N1: D42.1 (K), D43.2 (A)
LED_B_S1_N2: D43.1 (K), D44.2 (A)
LED_B_S2_N0: D45.1 (K), D46.2 (A)
LED_B_S2_N1: D46.1 (K), D47.2 (A)
LED_B_S2_N2: D47.1 (K), D48.2 (A)
LED_B_S3_N0: D49.1 (K), D50.2 (A)
LED_B_S3_N1: D50.1 (K), D51.2 (A)
LED_B_S3_N2: D51.1 (K), D52.2 (A)
LED_B_S4_N0: D53.1 (K), D54.2 (A)
LED_B_S4_N1: D54.1 (K), D55.2 (A)
LED_B_S4_N2: D55.1 (K), D56.2 (A)
LED_B_S5_N0: D57.1 (K), D58.2 (A)
LED_B_S5_N1: D58.1 (K), D59.2 (A)
LED_B_S5_N2: D59.1 (K), D60.2 (A)
LED_B_S6_N0: D61.1 (K), D62.2 (A)
LED_B_S6_N1: D62.1 (K), D63.2 (A)
LED_B_S6_N2: D63.1 (K), D64.2 (A)
LED_B_S7_N0: D65.1 (K), D66.2 (A)
LED_B_S7_N1: D66.1 (K), D67.2 (A)
LED_B_S7_N2: D67.1 (K), D68.2 (A)
NRST: D70.4 (IO3), J6.10 (~RESET), J7.3, R8.2, U7.6 (PF2)
NTC_SENSE: R98.2, RT1.1, U7.11 (PA4)
unnamed: BT1.1 (+), BT3.2 (-)
unnamed: BT2.1 (+), BT4.2 (-)
unnamed: BT3.1 (+), BT5.2 (-)
unnamed: BT4.1 (+), BT6.2 (-)
unnamed: BT5.1 (+), BT7.2 (-)
unnamed: BT6.1 (+), BT8.2 (-)
PACK_RAW: F1.2, Q3.2 (S)
PACK_RAW_F: F1.1, J2.1
PWM_A: U5.3 (EN), U7.13 (PA6)
PWM_B: U6.3 (EN), U7.14 (PA7)
Q3_GATE: Q3.1 (G), R90.1
STACK_NEG: BT1.2 (-), BT2.2 (-), J1.1, J2.2, R1.1
SWCLK: D70.3 (IO2), J6.4 (SWCLK/TCK), J7.2, U7.25 (PA14)
SWDIO: D70.1 (IO1), J6.2 (SWDIO/TMS), J7.1, U7.24 (PA13)
U4_FB: R2.2, R3.1, U4.4 (VFB)
U4_SW: C93.2, L1.1, U4.2 (SW)
U4_VBST: C93.1, U4.6 (VBST)
U5_COFF: C94.1, R94.2, U5.4 (COFF)
U5_CSN: R4.2, U5.7 (CSN)
U5_PGATE: Q4.1 (G), U5.6 (PGATE)
U5_SW: D3.1 (K), L2.1, Q4.3 (D)
U5_UVLO: R95.2, U5.1 (UVLO)
U5_VCC: C8.1, C9.1, U5.2 (IADJ), U5.9 (VCC)
U6_COFF: C95.1, R96.2, U6.4 (COFF)
U6_CSN: R5.2, U6.7 (CSN)
U6_PGATE: Q5.1 (G), U6.6 (PGATE)
U6_SW: D4.1 (K), L3.1, Q5.3 (D)
U6_UVLO: R97.2, U6.1 (UVLO)
U6_VCC: C10.1, C11.1, U6.2 (IADJ), U6.9 (VCC)
USB_DN: D2.2 (D-), J3.A7 (D-), J3.B7 (D-)
USB_DP: D2.1 (D+), J3.A6 (D+), J3.B6 (D+)
USB_VBUS: C1.1, C2.1, D2.6 (VBUS), J3.A4 (VBUS), J3.A9 (VBUS), J3.B4 (VBUS), J3.B9 (VBUS)
VBAT: BT7.1 (+), BT8.1 (+), C6.1, D1.1 (A1), J1.5, Q1.5 (D), Q3.3 (D), R90.2, U4.3 (VIN), U4.5 (EN)
VBAT_PROT: Q2.5 (D), Q4.2 (S), Q5.2 (S), R94.1, R95.1, R96.1, R97.1, U5.10 (VIN), U6.10 (VIN)

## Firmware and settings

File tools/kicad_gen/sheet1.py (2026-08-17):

"""
Sheet 1 -- Battery Pack & Protection.

Topology notes (flagged where it deviates from / extends the literal BOM
table in the project prompt):

- 4S2P pack, series taps bottom->top: STACK_NEG - TAP1 - TAP2 - TAP3 - VBAT.
  BT1/BT2 parallel across STACK_NEG..TAP1, BT3/BT4 across TAP1..TAP2,
  BT5/BT6 across TAP2..TAP3, BT7/BT8 across TAP3..VBAT.
- U1 (BQ76920PW) VC0..VC4 sense the 4 taps; VC5 tied to VC4 (top) per TI's
  datasheet convention for <5S configurations. BAT/REGSRC = VBAT (top).
- R1 (current-sense shunt) sits between STACK_NEG and GND -- so BQ76920 can
  coulomb-count return current -- while the two protection FETs (Q1/Q2)
  sit HIGH-SIDE, in series between VBAT and VBAT_PROT, per the brief's own
  net map (VBAT and VBAT_PROT are both positive rails; GND is the one
  common ground). SRP=STACK_NEG (battery side), SRN=GND (system side).
- Q1 (DSG) and Q2 (CHG) are wired classic back-to-back / shared-source:
  Q1 D=VBAT, S=FET_MID; Q2 D=VBAT_PROT, S=FET_MID. Body diodes oppose,
  so either FET alone blocks one current direction when off.
- Q3 (AO3401A) is a P-FET "ideal diode" reverse-polarity guard right after
  the pack connector J2: S=PACK_RAW (from J2/F1), D=VBAT, G pulled to VBAT
  through added R90 so it self-biases on once VBAT is established -- same
  validated technique as a prior project's Q1 reverse-polarity circuit.
- FLAGGED ADDITIONS (not itemized as separate BOM rows in the prompt, but
  required for the listed ICs to actually function per their own
  datasheets -- see docs/design_notes.md):
    C90 1uF  0603  -- U1 REGOUT decoupling (BQ76920 datasheet typ. app. circuit)
    C91 0.1uF 0603 -- U1 CAP1 decoupling   (BQ76920 datasheet typ. app. circuit)
    R90 100k 0603  -- Q3 gate self-bias pull-up to VBAT (ideal-diode topology)
- U1 pins TS1 (no battery-pack thermistor in this BOM) and ALERT (not
  wired to an MCU GPIO in the given net map) are left as explicit
  no-connects, flagged for user awareness rather than silently guessed.
"""
import sys, os
sys.path.insert(0, os.path.dirname(os.path.dirname(os.path.abspath(__file__))))
from kicad_gen.builder import (
    build_schematic, add_part, add_pwr_flag, write_and_upgrade, Part,
)

PROJECT = "red-light-panel"
SHEET = "1"


def build():
    sch = build_schematic("Battery Pack & Protection", "01_battery_protection")
    embedded = set()

    def P(**kw):
        kw.setdefault("sheet", SHEET)
        return Part(**kw)

    parts = []

    # --- 4S2P cell stack ---
    cell_nets = [
        ("BT1", 20, "TAP1", "STACK_NEG"), ("BT2", 20, "TAP1", "STACK_NEG"),
        ("BT3", 40, "TAP2", "TAP1"), ("BT4", 40, "TAP2", "TAP1"),
        ("BT5", 60, "TAP3", "TAP2"), ("BT6", 60, "TAP3", "TAP2"),
        ("BT7", 80, "VBAT", "TAP3"), ("BT8", 80, "VBAT", "TAP3"),
    ]
    for i, (ref, col, plus, minus) in enumerate(cell_nets):
        x = 20 + col
        y = 20 if ref in ("BT1", "BT3", "BT5", "BT7") else 40
        parts.append(P(ref=ref, lib_file="Device", entry_name="Battery_Cell", nickname="Device",
                       value="INR18650-30Q", footprint="Battery:BatteryHolder_Keystone_1042_1x18650",
                       pins={"1": plus, "2": minus}, x=x, y=y,
                       mpn="Samsung INR18650-30Q", manufacturer="Samsung SDI",
                       digikey_pn="INR18650-30Q-B-ND",
                       datasheet="https://www.dnkpower.com/wp-content/uploads/2018/10/INR18650-30Q.pdf"))

    # --- protection AFE ---
    parts.append(P(ref="U1", lib_file="Battery_Management", entry_name="BQ76920PW", nickname="Battery_Management",
                   value="BQ76920PW", footprint="Package_SO:TSSOP-20_4.4x6.5mm_P0.65mm",
                   pins={"1": "DSG_GATE", "2": "CHG_GATE", "3": "GND", "4": "I2C_SDA", "5": "I2C_SCL",
                         "6": "NC", "7": "U1_CAP1", "8": "U1_REGOUT", "9": "VBAT", "10": "VBAT",
                         "11": "NC", "12": "VBAT", "13": "VBAT", "14": "TAP3", "15": "TAP2",
                         "16": "TAP1", "17": "STACK_NEG", "18": "STACK_NEG", "19": "GND", "20": "NC"},
                   x=140, y=60, mpn="BQ7692000PWR", manufacturer="Texas Instruments",
                   digikey_pn="296-37299-1-ND", datasheet="http://www.ti.com/lit/ds/symlink/bq76920.pdf"))

    # --- protection FETs (high-side, back-to-back) ---
    parts.append(P(ref="Q1", lib_file="Transistor_FET", entry_name="CSD18540Q5B", nickname="Transistor_FET",
                   value="CSD18540Q5B", footprint="Package_TO_SOT_SMD:TDSON-8-1",
                   pins={"1": "FET_MID", "2": "FET_MID", "3": "FET_MID", "4": "DSG_GATE", "5": "VBAT"},
                   x=200, y=20, mpn="CSD18540Q5B", manufacturer="Texas Instruments",
                   digikey_pn="296-37312-1-ND", datasheet="http://www.ti.com/lit/gpn/csd18540q5b"))
    parts.append(P(ref="Q2", lib_file="Transistor_FET", entry_name="CSD18540Q5B", nickname="Transistor_FET",
                   value="CSD18540Q5B", footprint="Package_TO_SOT_SMD:TDSON-8-1",
                   pins={"1": "FET_MID", "2": "FET_MID", "3": "FET_MID", "4": "CHG_GATE", "5": "VBAT_PROT"},
                   x=200, y=45, mpn="CSD18540Q5B", manufacturer="Texas Instruments",
                   digikey_pn="296-37312-1-ND", datasheet="http://www.ti.com/lit/gpn/csd18540q5b"))

    # --- reverse-polarity ideal diode ---
    parts.append(P(ref="Q3", lib_file="Transistor_FET", entry_name="AO3401A", nickname="Transistor_FET",
                   value="AO3401A", footprint="Package_TO_SOT_SMD:SOT-23",
                   pins={"1": "Q3_GATE", "2": "PACK_RAW", "3": "VBAT"},
                   x=90, y=90, mpn="AO3401A", manufacturer="Alpha & Omega Semiconductor",
                   digikey_pn="AO3401A-DICT-ND", datasheet="http://www.aosmd.com/pdfs/datasheet/AO3401A.pdf"))
    parts.append(P(ref="R90", lib_file="Device", entry_name="R", nickname="Device",
                   value="100k", footprint="Resistor_SMD:R_0603_1608Metric",
                   pins={"1": "Q3_GATE", "2": "VBAT"}, x=110, y=90,
                   mpn="RC0603FR-07100KL", manufacturer="Yageo", digikey_pn="311-100KHRCT-ND",
                   datasheet=""))

    # --- current sense ---
    parts.append(P(ref="R1", lib_file="Device", entry_name="R", nickname="Device",
                   value="0.01R 1%", footprint="Resistor_SMD:R_Shunt_Vishay_WSK2512_6332Metric_T2.21mm",
                   pins={"1": "STACK_NEG", "2": "GND"}, x=140, y=100,
                   mpn="WSL2512R0100FEA", manufacturer="Vishay Dale", digikey_pn="541-2455-1-ND",
                   datasheet="https://www.vishay.com/docs/30112/wsl.pdf"))

    # --- bus TVS + fuse ---
    parts.append(P(ref="D1", lib_file="Diode", entry_name="SMAJ24CA", nickname="Diode",
                   value="SMAJ24CA", footprint="Diode_SMD:D_SMA",
                   pins={"1": "VBAT", "2": "GND"}, x=90, y=110,
                   mpn="SMAJ24CA", manufacturer="Littelfuse", digikey_pn="F5351CT-ND",
                   datasheet="https://www.littelfuse.com/media?itemid=75e32973-b177-4ee3-a0ff-cedaf1abdb93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"))
    parts.append(P(ref="F1", lib_file="Device", entry_name="Fuse", nickname="Device",
                   value="0.25A resettable", footprint="Fuse:Fuse_BelFuse_0ZRE0025FF_L9.6mm_W3.8mm",
                   pins={"1": "PACK_RAW_F", "2": "PACK_RAW"}, x=60, y=90,
                   mpn="0ZRE0025FF (corrected from placeholder MICROSMD250F/16-2 -- FLAG FOR REVIEW)",
                   manufacturer="Bel Fuse", digikey_pn="507-1677-1-ND",
                   datasheet="https://www.belfuse.com/resources/datasheets/circuitprotection/ds-cp-0zre-series.pdf"))

    # --- connectors ---
    parts.append(P(ref="J1", lib_file="Connector_Generic", entry_name="Conn_01x05", nickname="Connector_Generic",
                   value="JST B5B-XH-A", footprint="Connector_JST:JST_XH_B5B-XH-A_1x05_P2.50mm_Vertical",
                   pins={"1": "STACK_NEG", "2": "TAP1", "3": "TAP2", "4": "TAP3", "5": "VBAT"},
                   x=140, y=20, mpn="B5B-XH-A", manufacturer="JST", digikey_pn="455-1719-ND",
                   datasheet="https://www.jst-mfg.com/product/pdf/eng/eXH.pdf"))
    parts.append(P(ref="J2", lib_file="Connector_Generic", entry_name="Conn_01x02", nickname="Connector_Generic",
                   value="Molex 43045-0200", footprint="Connector_Molex:Molex_Micro-Fit_3.0_43045-0200_2x01_P3.00mm_Horizontal",
                   pins={"1": "PACK_RAW_F", "2": "STACK_NEG"}, x=20, y=90,
                   mpn="43045-0200", manufacturer="Molex", digikey_pn="WM1857-ND",
                   datasheet="https://www.molex.com/pdm_docs/sd/430450200_sd.pdf"))

    # --- flagged-added support passives (see module docstring) ---
    parts.append(P(ref="C90", lib_file="Device", entry_name="C", nickname="Device",
                   value="1uF (added, flagged)", footprint="Capacitor_SMD:C_0603_1608Metric",
                   pins={"1": "U1_REGOUT", "2": "GND"}, x=170, y=100,
                   mpn="", manufacturer="", digikey_pn="", datasheet=""))
    parts.append(P(ref="C91", lib_file="Device", entry_name="C", nickname="Device",
                   value="0.1uF (added, flagged)", footprint="Capacitor_SMD:C_0603_1608Metric",
                   pins={"1": "U1_CAP1", "2": "GND"}, x=185, y=100,
                   mpn="", manufacturer="", digikey_pn="", datasheet=""))

    for part in parts:
        add_part(sch, part, PROJECT, embedded)

    # Cross-sheet exposure: every pin already carries a GlobalLabel (see
    # add_part), and GlobalLabel scope is project-wide by definition, so
    # VBAT/VBAT_PROT/I2C_SDA/I2C_SCL/GND are already visible to every other
    # sheet that places a same-named label at one of ITS pins -- no extra
    # sheet-symbol pins or root-sheet wiring needed. See
    # docs/design_notes.md "Why global labels instead of sheet pins".

    # GND has no genuine power_out driver anywhere in the project, so it
    # gets a flag on every sheet that uses it. VBAT is NOT flagged here --
    # sheet 2's BQ25792 BAT pin (power_out) is a genuine driver for this
    # net project-wide, and PWR_FLAG conflicts with a real power_out pin
    # on the same net once the hierarchy is ERC'd together (confirmed
    # empirically; see docs/design_notes.md).
    add_pwr_flag(sch, "GND", 260, 90, embedded, flag_id="1")

    out = "/Users/lucaspoulos/kicad-projects/red-light-panel/01_battery_protection.kicad_sch"
    print(write_and_upgrade(sch, out))


if __name__ == "__main__":
    build()

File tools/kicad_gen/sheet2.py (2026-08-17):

"""
Sheet 2 -- USB-C Charging Input.

Both U2 (TPS25751DREFR, PD sink controller + integrated power-path switch)
and U3 (BQ25792RQMR, buck-boost charger) are hand-built symbols (see
libs/*.kicad_sym and README.md "Known open items" -- the research that
sourced them flagged several individual pin-electrical-type judgment calls
on ambiguous datasheet entries). This sheet's own topology adds more
judgment calls of its own, all flagged here rather than silently guessed:

- **TPS25751 PPHV/DRAIN power path**: TI's datasheet is ambiguous about
  which side of the internal FET is which (both pin groups have entries
  flagged "N/A"/"I/O" by TI directly). Modeled here as: VBUS_IN (from the
  connector) -> internal switch -> PPHV/DRAIN tied together as one node
  "PD_PP_OUT" -> feeds BQ25792's VBUS. This is a best-effort interpretation,
  not confirmed against TI's own reference design -- FLAG FOR REVIEW.
- **TPS25751 PP5V tied to VBUS_IN**: assumes a fixed-5V/no-PD-negotiated
  bootstrap path for the controller's own bias rail. FLAG FOR REVIEW.
- **BQ25792 ACDRV1/ACDRV2/BTST1/BTST2 left NC**: TI's real BQ25792
  reference design needs external ACFET/RBFET1/RBFET2 ideal-diode MOSFETs
  driven from these pins -- NOT itemized in the original BOM. Rather than
  invent 2-3 more MOSFETs and their part numbers unprompted, these pins
  are left explicit no-connects and flagged here for the user to decide
  whether to add that front-end. **This means the charger's front-end
  reverse-blocking/ideal-diode stage is incomplete as generated.**
- **BQ25792 SW1/SW2 buck-boost inductor**: REQUIRED for the charger to
  function at all, but not itemized as a separate BOM row. Added as L90,
  flagged, placeholder 2.2uH/hand-wound-class footprint -- exact
  inductance/saturation-current needs a real calculation against your
  target charge current, not just default value here.
- **BQ25792 ILIM_HIZ / PROG resistors**: analog set-point pins, each need
  an external resistor per TI's design equations. Added as R91/R92,
  flagged, placeholder values.
- **BQ25792 CE/QON tied directly to GND**: always-enabled simplification
  (no MCU GPIO reserved for charge-enable in the given net map).
- **I2C bus assignment**: per the brief's own net map ("I2C_SDA, I2C_SCL
  ... Sheet 6 MCU -> Sheets 1 and 2, BQ76920 and BQ25792"), the MCU talks
  directly to BQ25792 over the shared I2C_SDA/I2C_SCL bus. TPS25751's
  *controller-facing* bus (I2Ct_SDA/SCL) is wired to that same shared bus;
  its *companion* bus (I2Cc_SDA/SCL/IRQ) is left NC since this design
  doesn't use a private PD-to-charger side channel.
- **D8 status LED is single-color** (per your decision -- the original BOM
  MPN wasn't a real bi-color part): only STAT_LED_R is used, driven from
  BQ25792's STAT pin, matching the brief's own net-map line.
- **J3 exact GCT USB4105 suffix**: plating/stake-length TBD (there is no
  "mount style" suffix -- confirmed by research, the whole series is one
  fixed SMT top-mount style). Defaulted to USB4105-GF-A (standard gold
  flash plating, 0.95mm stake) -- FLAG FOR REVIEW against your actual
  reel/tape spec.
"""
import sys, os
sys.path.insert(0, os.path.dirname(os.path.dirname(os.path.abspath(__file__))))
from kicad_gen.builder import build_schematic, add_part, add_pwr_flag, write_and_upgrade, Part

PROJECT = "red-light-panel"
SHEET = "2"


def build():
    sch = build_schematic("USB-C Charging Input", "02_usbc_charging")
    embedded = set()

    def P(**kw):
        kw.setdefault("sheet", SHEET)
        return Part(**kw)

    parts = []

    parts.append(P(ref="J3", lib_file="Connector", entry_name="USB_C_Receptacle_USB2.0_16P", nickname="Connector",
                   value="USB4105-GF-A (plating/stake length TBD, flag)",
                   footprint="Connector_USB:USB_C_Receptacle_GCT_USB4105-xx-A_16P_TopMnt_Horizontal",
                   pins={"A1": "GND", "A4": "USB_VBUS", "A5": "CC1", "A6": "USB_DP", "A7": "USB_DN",
                         "A8": "NC", "A9": "USB_VBUS", "A12": "GND", "B1": "GND", "B4": "USB_VBUS",
                         "B5": "CC2", "B6": "USB_DP", "B7": "USB_DN", "B8": "NC", "B9": "USB_VBUS",
                         "B12": "GND", "SH": "GND"},
                   x=20, y=20, mpn="USB4105-GF-A", manufacturer="GCT",
                   digikey_pn="GCT USB4105-GF-A-ND (verify exact DigiKey SKU)",
                   datasheet="https://gct.co/files/drawings/usb4105.pdf"))

    parts.append(P(ref="D2", lib_file="PROJECT", project_symbol="TPD4S012DRYR", entry_name="TPD4S012DRYR", nickname="red-light-panel",
                   value="TPD4S012DRYR (corrected from BOM's TPD4S012DBVR -- flag)",
                   footprint="Package_SON:Texas_USON-6_1x1.45mm_P0.5mm_SMD",
                   pins={"1": "USB_DP", "2": "USB_DN", "3": "NC", "4": "GND", "5": "NC", "6": "USB_VBUS"},
                   x=60, y=20, mpn="TPD4S012DRYR", manufacturer="Texas Instruments",
                   digikey_pn="296-TPD4S012DRYRCT-ND", datasheet="https://www.ti.com/lit/ds/symlink/tpd4s012.pdf"))

    parts.append(P(ref="C1", lib_file="Device", entry_name="C", nickname="Device",
                   value="10uF", footprint="Capacitor_SMD:C_1206_3216Metric",
                   pins={"1": "USB_VBUS", "2": "GND"}, x=20, y=45,
                   mpn="CC1206KKX7R8BB106", manufacturer="Yageo", digikey_pn="311-4622-1-ND", datasheet=""))
    parts.append(P(ref="C2", lib_file="Device", entry_name="C", nickname="Device",
                   value="10uF", footprint="Capacitor_SMD:C_1206_3216Metric",
                   pins={"1": "USB_VBUS", "2": "GND"}, x=35, y=45,
                   mpn="CC1206KKX7R8BB106", manufacturer="Yageo", digikey_pn="311-4622-1-ND", datasheet=""))
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

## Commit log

2026-08-17 Initial repo scaffold: README, CERN-OHL-P v2 license, KiCad .gitignore
    - Standard KiCad gitignore (github/gitignore community template) with a
    narrow exception to track the generated bom/*.csv
    - CERN-OHL-P v2 (permissive open hardware license), fetched verbatim from
    SPDX license-list-data
    - Placeholder README, libs/ and docs/ scaffolding
2026-08-17 KiCad 10 project scaffold, project-local lib tables, schematic generator tooling
    - red-light-panel.kicad_pro / .kicad_pcb: minimal valid KiCad 10 skeletons,
    bootstrapped by hand-writing a KiCad 8-era seed and running
    'kicad-cli sch/pcb upgrade --force' so the format is authoritatively
    generated by KiCad 10 itself, not guessed (version 20260306/20260206,
    generator_version 10.0, confirmed against the installed kicad-cli 10.0.5).
    - sym-lib-table / fp-lib-table: project-scoped, registering only the exact
    stock libraries this design needs (via ${KICAD10_SYMBOL_DIR}/
    ${KICAD10_FOOTPRINT_DIR}) plus a project-local libs/ via ${KIPRJMOD}, so
    the repo is self-contained and doesn't depend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
    [red-light-panel.kicad_pcb]
2026-08-17 Sheet 1: Battery Pack & Protection (4S2P, BQ76920 AFE, high-side FET protection)
    0 ERC errors in isolation except the expected cross-sheet I2C_SCL driver
    dependency (MCU lives on sheet 6); see tools/kicad_gen/sheet1.py docstring
    for topology notes and flagged additions (C90/C91 BQ76920 decoupling,
    R90 Q3 gate self-bias -- required by datasheet app circuits, not itemized
    as separate BOM rows in the original part list).
    [01_battery_protection.kicad_sch]
2026-08-17 Sheet 2: USB-C Charging Input (TPS25751 PD controller + BQ25792 buck-boost charger)
    Merged all 5 hand-built project-local symbols into libs/red-light-panel.kicad_sym
    (matching the single project-local sym-lib-table entry). Fixed duplicate-pad
    pins on BQ25792 (BAT) and TPS25751 (VBUS) from power_out to passive -- ERC
    correctly flagged two power_out pins tied together as a conflict even
    though they're the same physical lead on the IC.
    0 ERC errors except the two expected cross-sheet dependencies (I2Ct_SCL
    driven by the MCU on sheet 6; VIN_3V3 driven by sheet 3's buck regulator).
    See tools/kicad_gen/sheet2.py docstring for the substantial list of
    flagged topology judgment calls (TPS25751 power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
    [01_battery_protection.kicad_sch, 02_usbc_charging.kicad_sch]
2026-08-17 Sheet 3: 3.3V Logic Rail (TPS563201 buck, calculated feedback divider)
    0 ERC errors except expected cross-sheet VIN<-VBAT dependency (sheet 2).
    Added C93 VBST bootstrap cap (datasheet-required, not in original BOM).
    R3 value calculated from TPS563201's 0.768V reference -- flagged for
    verification. L1 footprint is a size-matched placeholder (no exact Wurth
    744031220 footprint in stock libraries) -- flagged, matches the brief's
    pre-existing inductor-value open item.
    [03_power_rail_3v3.kicad_sch]
2026-08-17 Sheet 4: LED Drivers (2ch, LM3409HV PFET-buck topology)
    Q4/Q5 AO3401A already satisfies the brief's '30V margin, not 20V' flag
    (rated -30V Vds). 0 ERC errors except expected cross-sheet EN<-PWM_A/B
    dependency (sheet 6 MCU). Added COFF timing network and UVLO pull-up per
    channel (datasheet-required, not itemized as separate BOM rows) --
    flagged for frequency/threshold verification. Added VBAT_PROT PWR_FLAG
    here since its only project-wide source (sheet 1's protection FET drain)
    is passive-typed, not power_out.
    [04_led_drivers.kicad_sch]
2026-08-17 Sheet 5: LED Array (64x Luminus SST-10-DR, 2ch x 8 parallel x 4 series)
    0 ERC errors (only expected benign warnings: project-local footprint
    library not in global config, endpoint-off-grid cosmetics). Topology
    (8 parallel strings of 4 series LEDs per channel) is derived/flagged, not
    specified by the original BOM -- see sheet5.py docstring for the Vf/
    current-budget reasoning and the ~74W power-budget verification flag.
    Built a custom 3-pad 3535 footprint (libs/red-light-panel.pretty/) since
    no exact match exists in KiCad's stock libraries. Added R98 NTC pull-up
    divider resistor (datasheet-required, not itemized as separate BOM row).
    [05_led_array.kicad_sch]
2026-08-17 Sheet 6: MCU & Control (STM32G031K8T6, SWD debug, ESD arrays)
    0 ERC errors except expected cross-sheet VDD/VCC<-3V3 dependency (sheet 3).
    GPIO pin assignment (I2C on PB6/PB7, PWM on PA6/PA7, buttons on PA0-PA3,
    NTC ADC on PA4, NRST on PF2) is derived/flagged -- not specified by the
    BOM, and not verified against the STM32G031 reference manual's alternate-
    function table. Wired D6/D7 (corrected TPD4E001DBVR, from BOM's
    TPD4E001DZDR) across the button inputs and SWD lines respectively.
    [06_mcu_control.kicad_sch]
2026-08-17 Sheet 7: HMI (4 buttons + single-color status LED)
    0 ERC errors. D8 built as single-color (per your decision), driven from
    BQ25792's open-collector STAT pin (sheet 2) through current-limit R13.
    [07_hmi.kicad_sch]
2026-08-17 Root sheet + full-hierarchy fixes (PWR_FLAG uniqueness, annotation, D-designator collision)
    - red-light-panel.kicad_sch: 7 sheet symbols, no sheet-pins (global-label
    connectivity throughout, see docs/design_notes.md).
    - tools/kicad_gen/fix_instance_paths.py: one-time pass populating each
    sub-sheet's per-symbol instances block with the real root-relative path
    (kicad-cli sch upgrade was silently emptying these -- invisible to ERC,
    but kicad-cli sch export bom flagged it as an annotation error).
    - Fixed: multiple PWR_FLAGs on the same merged net conflicting with each
    other at full-hierarchy scale (now exactly one per net, project-wide);
    duplicate unnumbered '#FLG' references across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
    [01_battery_protection.kicad_sch, 02_usbc_charging.kicad_sch, 03_power_rail_3v3.kicad_sch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]
2026-08-17 BOM generation script + initial CSV
    bom/generate_bom.py wraps kicad-cli sch export bom (which already reads
    the full hierarchical netlist including custom fields and has built-in
    grouping) rather than hand-rolling a parser. Groups by (MPN, Value,
    Footprint) -- not MPN alone, since several flagged-added support passives
    share an empty MPN and would otherwise incorrectly merge. 48 BOM rows,
    153 total placed components, zero blank footprints.
    [red-light-panel-bom.csv]
2026-08-17 Docs: README, CHANGELOG, block diagram + power budget stubs
    Consolidated the full list of flagged open items (BOM corrections,
    engineering judgment calls) into README.md 'Known open items' section.
2026-08-17 PCB fab rules: 2-layer 1oz/1oz, JLCPCB standard service + margin
    - kicad_pcb: explicit stackup (1oz/1oz copper, 1.53mm FR4 core, 1.6mm
    overall, ENIG finish -- flagged upgrade from JLC's HASL default given
    this board's 0.4mm-pitch QFN parts).
    - kicad_pro design rules: track width/clearance 0.15mm (6mil, ~1.7x
    JLCPCB's 3.5mil minimum), hole-to-copper 0.3mm, hole-to-hole 0.5mm,
    silk line/clearance 0.15mm, min text height 1.0mm -- every constraint
    set with margin above JLCPCB's published standard-service minimum, not
    at the limit.
    - red-light-panel.kicad_dru: net-specific high-current trace-width
    overrides (1-1.5mm) for VBAT/VBAT_PROT/GND/USB_VBUS/LED channel/
    switching-node nets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
    [red-light-panel.kicad_pcb]
2026-08-17 Schematic: replace global-label power nets with real power symbols
    GND, VBAT, VBAT_PROT, 3V3, and USB_VBUS now get an actual KiCad power
    symbol at every pin (power:GND, power:+3V3 with Value overridden to
    '3V3', power:VBUS overridden to 'USB_VBUS', and two custom symbols for
    VBAT/VBAT_PROT copied from stock power:+BATT into
    libs/red-light-panel.kicad_sym) instead of a plain GlobalLabel -- the
    idiomatic convention for power rails. All other cross-sheet signal nets
    (I2C, PWM, LED channel outputs, etc.) remain GlobalLabels, which still
    makes sense for data/PWM signals.
    Confirmed empirically before rolling this out: overriding a stock power
    symbol's Value does change its effective net name (pow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
    [01_battery_protection.kicad_sch, 02_usbc_charging.kicad_sch, 03_power_rail_3v3.kicad_sch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]
2026-08-17 Reapply PCB fab rules (stackup + DRC margins) after GUI overwrite
    The KiCad GUI was left open from an earlier session and silently reverted
    the previous fab-rules commit (446f7ae) when it autosaved with its own
    stale in-memory project state -- stackup was gone, DRC minimums were back
    to KiCad's stock defaults. Closed KiCad first this time, then reapplied
    the same values directly to the files on disk so nothing is open to
    clobber them again. Same content as 446f7ae: 2-layer 1oz/1oz ENIG
    stackup, 0.15mm track/clearance, 0.3mm hole clearance, 0.5mm hole-to-hole,
    0.15mm silk clearance, 1.0mm min text height.
    Note: the same GUI session also appears to have re-synced some PCB pads
    to stale auto-g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
    [red-light-panel.kicad_pcb]
